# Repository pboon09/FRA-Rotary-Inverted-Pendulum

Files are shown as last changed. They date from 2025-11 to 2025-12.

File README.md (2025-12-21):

# FRA421 Embedded Systems Final Project

## Overview

Advanced embedded system implementation with state estimation filters, multiple interfaces, and safety-critical design for Rotary Inverted Pendulum control.

## Features

### State Estimation
- ✅ **Kalman Filter** - Optimal velocity estimation from encoder positions
- ✅ **Low-Pass Filter** - Noise reduction
- ✅ **CMSIS DSP Library** - Optimized signal processing

### Multi-Interface System
- ✅ **Colors Shield LED (8×8)** - End-effector position visualization
- ✅ **LCD Display** - Real-time joint position and velocity display
- ✅ **SD Card Logging** - Position/velocity data logging
- ✅ **Bluetooth (HC-05)** - Wireless command interface

### Safety & Efficiency
- ✅ **Safety-critical programming** - Fault detection, graceful degradation
- ✅ **Low Power Modes** - Sleep modes during idle periods
- ✅ **Watchdog Timer** - System reliability

### Hardware Integration
- ✅ **Custom PCB** - All interfaces integrated on single board
- ✅ **Non-blocking architecture** - Concurrent interface operation

## System Architecture
```
STM32 NUCLEO-G474RE
    ├─ Encoders (AMT103-V) → Kalman Filter → LQR Controller → Motor
    ├─ LED Matrix → End-effector position (X-Y grid)
    ├─ LCD → Position and velocity display
    ├─ SD Card → CSV data logging
    └─ Bluetooth → Command reception (start/stop/config)
```

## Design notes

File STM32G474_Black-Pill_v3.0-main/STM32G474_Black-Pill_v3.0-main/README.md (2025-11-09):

<!-- Improved compatibility of back to top link: See: https://github.com/othneildrew/Best-README-Template/pull/73 -->

<!--
*** Thanks for checking out the Best-README-Template. If you have a suggestion
*** that would make this better, please fork the repo and create a pull request
*** or simply open an issue with the tag "enhancement".
*** Don't forget to give the project a star!
*** Thanks again! Now go create something AMAZING! :D
-->

<!-- PROJECT SHIELDS -->
<!--
*** I'm using markdown "reference style" links for readability.
*** Reference links are enclosed in brackets [ ] instead of parentheses ( ).
*** See the bottom of this document for the declaration of the reference variables
*** for contributors-url, forks-url, etc. This is an optional, concise syntax you may use.
*** https://www.markdownguide.org/basic-syntax/#reference-style-links
-->
[][contributors-url]
[][forks-url]
[][stars-url]
[][issues-url]
[][license-url]


<!-- PROJECT LOGO -->
<br />
<div align="center">

<h3 align="center">Black Pill v3.0 STM32G474</h3>

  <p align="center">
    The STM32-Pills are compact and convenient for prototyping, but their digital focus leaves room for exploration. The STM32G474's integration of analog and digital components opens up possibilities for creating versatile systems. For example, the integrated opamps and comparators. 
    <br />
    <a href="https://github.com/nikolai2111/STM32G474_Black-Pill_v3.0"><strong>Explore the docs »</strong></a>
    <br />
    <br />
    <a href="https://github.com/nikolai2111/STM32G474_Black-Pill_v3.0">View Demo</a>
    ·
    <a href="https://github.com/nikolai2111/STM32G474_Black-Pill_v3.0/issues/new?labels=bug&template=bug-report---.md">Report Bug</a>
    ·
    <a href="https://github.com/nikolai2111/STM32G474_Black-Pill_v3.0/issues/new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">Request Feature</a>
  </p>
</div>

<!-- TABLE OF CONTENTS -->
<details>
  <summary>Table of Contents</summary>
  <ol>
    <li>
      <a href="#about-the-project">About The Project</a>
      <ul>
        <li><a href="#built-with">Built With</a></li>
      </ul>
    </li>
    <li>
      <a href="#getting-started">Getting Started</a>
      <ul>
        <li><a href="#prerequisites">Prerequisites</a></li>
        <li><a href="#installation">Installation</a></li>
      </ul>
    </li>
    <li><a href="#usage">Usage</a></li>
    <li><a href="#roadmap">Roadmap</a></li>
    <li><a href="#contributing">Contributing</a></li>
    <li><a href="#license">License</a></li>
    <li><a href="#contact">Contact</a></li>
  </ol>
</details>

<!-- ABOUT THE PROJECT -->
## About The Project

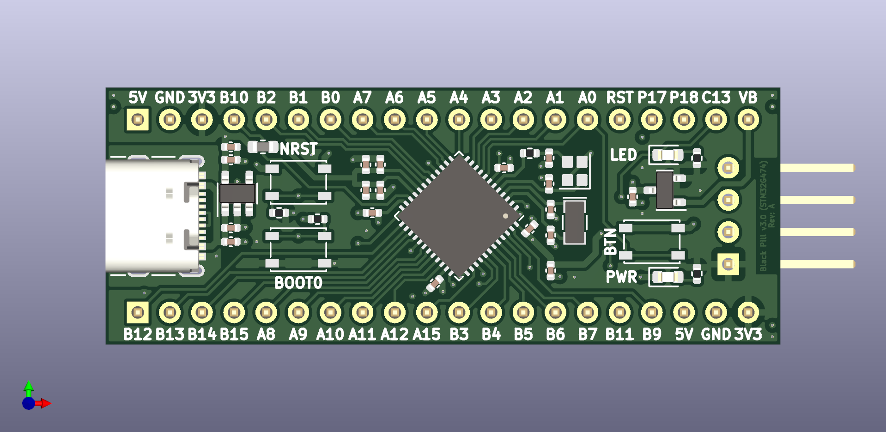
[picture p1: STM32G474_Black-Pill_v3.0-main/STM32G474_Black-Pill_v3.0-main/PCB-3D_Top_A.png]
Product Name Screen Shot
[](https://www.tindie.com/products/nikolai2111/black-pill-v30-stm32g474/)

I find the compact and versatile STM32-Pills (Blue and Black) intriguing due to their ease of use for various applications. They seamlessly integrate into hardware prototypes, simplifying the process of testing ideas. However, I’ve noticed that the existing Black Pills primarily focus on digital tasks.

On the other hand, the STM32G474 stands out as a fascinating microcontroller that bridges the gap between the digital and analog worlds. What piques my interest are its integrated analog components, such as op-amps and comparators, coupled with digital interfaces. This combination offers an exciting opportunity to develop systems that seamlessly blend both digital and analog functionalities.

In summary, while the compact and convenient Pills are fascinating tools for rapid prototyping, their current digital focus leaves room for exploration. In contrast, the STM32G474’s integration of analog and digital components opens up exciting possibilities for creating versatile, boundary-pushing systems.

<p align="right">(<a href="#readme-top">back to top</a>)</p>

### Built With

* [][Kicad-url]

<p align="right">(<a href="#readme-top">back to top</a>)</p>

<!-- GETTING STARTED -->
## Getting Started

### Prerequisites

Install KiCad 8.0 on your computer.

### Installation

ToDo:
1. Clone the repo to your STM32CubeIDE workspace
   ```sh
   git clone https://github.com/nikolai2111/STM32G474_Black-Pill_v3.0.git
   ```
2. Navigate to the the `src` folder.
3. Open the [project file](src/STM32G474_Black-Pill_v3.0.kicad_pro).

<p align="right">(<a href="#readme-top">back to top</a>)</p>

<!-- USAGE EXAMPLES -->
## Usage

Use this dev board with the template from [this repo](https://github.com/nikolai2111/STM32G474_Black-Pill_v3.0_Template). It's an example file.

<p align="right">(<a href="#readme-top">back to top</a>)</p>

<!-- ROADMAP -->
## Roadmap

- [ ] SW: Publish HAL template for this board.
- [ ] SW: Add LL template for this board.

See the [open issues](https://github.com/nikolai2111/STM32G474_Black-Pill_v3.0/issues) for a full list of proposed features (and known issues).

<p align="right">(<a href="#readme-top">back to top</a>)</p>

<!-- CONTRIBUTING -->
## Contributing

Contributions are what make the open source community such an amazing place to learn, inspire, and create. Any contributions you make are **greatly appreciated**.

If you have a suggestion that would make this better, please fork the repo and create a pull request. You can also simply open an issue with the tag "enhancement".
Don't forget to give the project a star! Thanks again!

1. Fork the Project
2. Create your Feature Branch (`git checkout -b feature/AmazingFeature`)
3. Commit your Changes (`git commit -m 'Add some AmazingFeature'`)
4. Push to the Branch (`git push origin feature/AmazingFeature`)
5. Open a Pull Request

<p align="right">(<a href="#readme-top">back to top</a>)</p>

<!-- LICENSE -->
## License

Distributed under the CERN-OHL-P-2.0 License. See `LICENSE.txt` for more information.

<p align="right">(<a href="#readme-top">back to top</a>)</p>

<!-- CONTACT -->
## Contact

Nikolai Zoller - nikolai.zoller@hotmail.com

Project Link: [https://github.com/nikolai2111/STM32G474_Black-Pill_v3.0](https://github.com/nikolai2111/STM32G474_Black-Pill_v3.0)

<p align="right">(<a href="#readme-top">back to top</a>)</p>

---
Source: [Best-README-Template](https://github.com/othneildrew/Best-README-Template)

<!-- MARKDOWN LINKS & IMAGES -->
<!-- https://www.markdownguide.org/basic-syntax/#reference-style-links -->
[contributors-shield]: https://img.shields.io/github/contributors/nikolai2111/STM32G474_Black-Pill_v3.0.svg?style=for-the-badge
[contributors-url]: https://github.com/nikolai2111/STM32G474_Black-Pill_v3.0/graphs/contributors
[forks-shield]: https://img.shields.io/github/forks/nikolai2111/STM32G474_Black-Pill_v3.0.svg?style=for-the-badge
[forks-url]: https://github.com/nikolai2111/STM32G474_Black-Pill_v3.0/network/members
[stars-shield]: https://img.shields.io/github/stars/nikolai2111/STM32G474_Black-Pill_v3.0.svg?style=for-the-badge
[stars-url]: https://github.com/nikolai2111/STM32G474_Black-Pill_v3.0/stargazers
[issues-shield]: https://img.shields.io/github/issues/nikolai2111/STM32G474_Black-Pill_v3.0.svg?style=for-the-badge
[issues-url]: https://github.com/nikolai2111/STM32G474_Black-Pill_v3.0/issues
[license-shield]: https://img.shields.io/github/license/nikolai2111/STM32G474_Black-Pill_v3.0.svg?style=for-the-badge
[license-url]: https://github.com/nikolai2111/STM32G474_Black-Pill_v3.0/blob/master/LICENSE.txt
[product-screenshot]: PCB-3D_Top_A.png
[Kicad-url]: https://www.kicad.org/

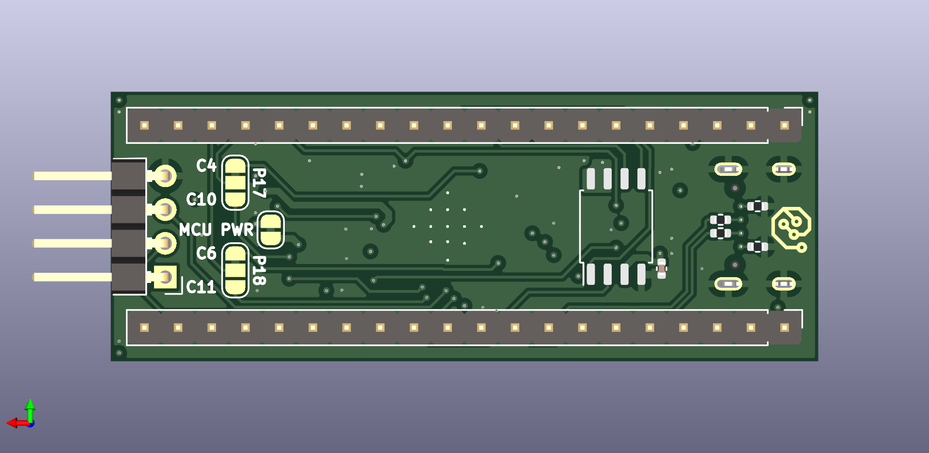
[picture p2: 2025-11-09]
STM32G474_Black-Pill_v3.0-main/STM32G474_Black-Pill_v3.0-main/PCB-3D_Bot_A.png

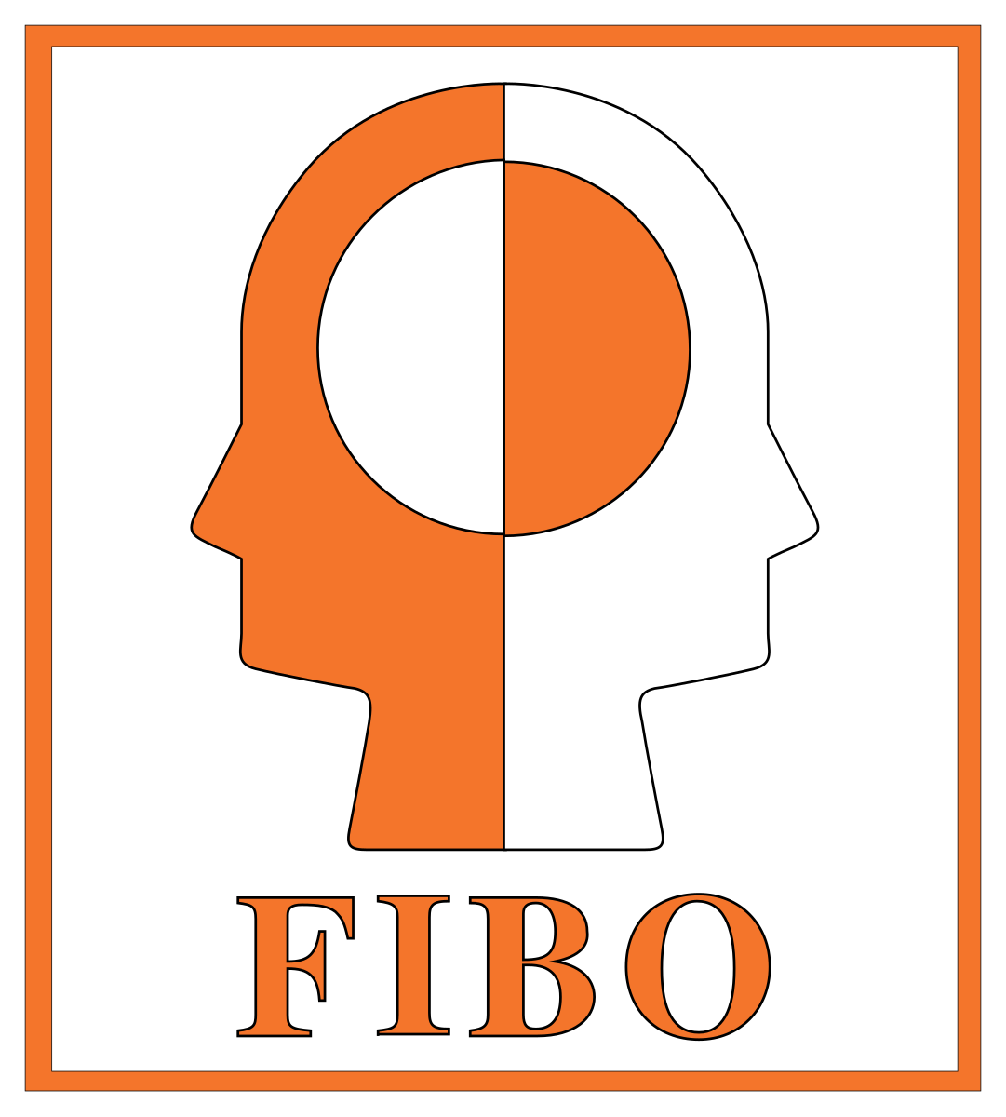
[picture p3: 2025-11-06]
RIP_ExtensionBoard/FIBO.svg.png

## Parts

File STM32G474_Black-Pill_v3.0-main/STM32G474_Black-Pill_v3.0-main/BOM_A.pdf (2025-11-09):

Reference | Value | Footprint | Manufacturer Part no. | Vendor | Vendor Part No. | Qty
C101, C104, C108-C110, C112, C114, C115, C119, C120 | 100nF | Capacitor_SMD:C_0402_1005Metric | GRM155R71C104KA88D | Digikey | 490-3261-1-ND | 10
C102, C103, C105, C106 | 6pF | Capacitor_SMD:C_0402_1005Metric | GRM1555C1H6R0BA01D | Digikey | 490-8221-1-ND | 4
C107 | 10µF | Capacitor_SMD:C_0402_1005Metric | GRM155R60J106ME15D | Digikey | 490-13238-1-ND | 1
C113, C116-C118 | 1µF | Capacitor_SMD:C_0402_1005Metric | GRM155C81C105KE11D | Digikey | 490-12700-1-ND | 4
D101 | red | LED_SMD:LED_0603_1608Metric | LTST-C190KRKT | Digikey | 160-1436-1-ND | 1
D102 | BAT54C | Package_TO_SOT_SMD:SOT-23 | BAT54C | Digikey | 4878-BAT54CCT-ND | 1
D103 | green | LED_SMD:LED_0603_1608Metric | LTST-C190KGKT | Digikey | 160-1435-1-ND | 1
J101 | USB_C_Receptacle_USB2.0 | Connector_USB:USB_C_Receptacle_GCT_USB4105-xx-A_16P_TopMnt_Horizontal | USB4105-GF-A | Digikey | 2073-USB4105-GF-ACT-ND | 1
J102, J103 | Conn_01x20 | Connector_PinHeader_2.54mm:PinHeader_1x20_P2.54mm_Vertical | - | From stock | - | 2
J104 | Conn_01x04 | Connector_PinHeader_2.54mm_User:PinHeader_1x04_P2.54mm_Horizontal_Board_Edge | - | From stock | - | 1
L101 | 10µH | Inductor_SMD:L_0603_1608Metric | MLZ1608M100WT000 | Digikey | 445-6389-1-ND | 1
R101, R102 | 5.1k | Resistor_SMD:R_0402_1005Metric | RC0402FR-075K1L | Digikey | 311-5.10KLRCT-ND | 2
R103, R108 | 10k | Resistor_SMD:R_0402_1005Metric | RC0402FR-0710KL | Digikey | 311-10.0KLRCT-ND | 2
R104, R105 | 10R | Resistor_SMD:R_0402_1005Metric | RC0402FR-0710RL | Digikey | 311-10.0LRCT-ND | 2
R106 | 0R | Resistor_SMD:R_0402_1005Metric | RC0402FR-070RL | Digikey | 311-0.0LRCT-ND | 1
R107, R109 | 100R | Resistor_SMD:R_0402_1005Metric | RC0402FR-07100RL | Digikey | 311-100LRCT-ND | 2
SW101-SW103 | SW_Push | Button_Switch_SMD:SW_SPST_PTS810 | PTS810 SJK 250 SMTR LFS | Digikey | CKN10503CT-ND | 3
U101 | W25Q32JVSS | Package_SO:SOIC-8_5.23x5.23mm_P1.27mm | W25Q32JVSSIQ | Digikey | W25Q32JVSSIQ-ND | 1
U102 | STM32G474CEUx | Package_DFN_QFN:QFN-48-1EP_7x7mm_P0.5mm_EP5.6x5.6mm | STM32G474CEU6 | Digikey | 497-STM32G474CEU6-ND | 1
U103 | AP7343xx | Package_TO_SOT_SMD:SOT-23-5 | AP7343-33W5-7 | Digikey | AP7343-33W5-7DICT-ND | 1
Y101 | 24MHz | Crystal:Crystal_SMD_SeikoEpson_FA128-4Pin_2.0x1.6mm | NX2016SA-24MHZ-EXS00A-CS10820 | Digikey | 644-1365-1-ND | 1
Y102 | 32.768kHz | Crystal:Crystal_SMD_MicroCrystal_CC7V-T1A-2Pin_3.2x1.5mm | NX3215SA-32.768KHZ-EXS00A-MU00525 | Digikey | 644-1386-1-ND | 1

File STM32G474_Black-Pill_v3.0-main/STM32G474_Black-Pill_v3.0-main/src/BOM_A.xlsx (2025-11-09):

Reference | Value | Footprint | Datasheet | Manufacturer Part no. | Vendor | Vendor Part No. | Qty
C101, C104, C108-C110, C112, C114, C115, C119, C120 | 100nF | Capacitor_SMD:C_0402_1005Metric | ~ | GRM155R71C104KA88D | Digikey | 490-3261-1-ND | 10
C102, C103, C105, C106 | 6pF | Capacitor_SMD:C_0402_1005Metric | ~ | GRM1555C1H6R0BA01D | Digikey | 490-8221-1-ND | 4
C107 | 10µF | Capacitor_SMD:C_0402_1005Metric | ~ | GRM155R60J106ME15D | Digikey | 490-13238-1-ND | 1
C113, C116-C118 | 1µF | Capacitor_SMD:C_0402_1005Metric | ~ | GRM155C81C105KE11D | Digikey | 490-12700-1-ND | 4
D101 | red | LED_SMD:LED_0603_1608Metric | ~ | LTST-C190KRKT | Digikey | 160-1436-1-ND | 1
D102 | BAT54C | Package_TO_SOT_SMD:SOT-23 | http://www.diodes.com/_files/datasheets/ds11005.pdf | BAT54C | Digikey | 4878-BAT54CCT-ND | 1
D103 | green | LED_SMD:LED_0603_1608Metric | ~ | LTST-C190KGKT | Digikey | 160-1435-1-ND | 1
J101 | USB_C_Receptacle_USB2.0 | Connector_USB:USB_C_Receptacle_GCT_USB4105-xx-A_16P_TopMnt_Horizontal | https://www.usb.org/sites/default/files/documents/usb_type-c.zip | USB4105-GF-A | Digikey | 2073-USB4105-GF-ACT-ND | 1
J102, J103 | Conn_01x20 | Connector_PinHeader_2.54mm:PinHeader_1x20_P2.54mm_Vertical | ~ | - | From stock | - | 2
J104 | Conn_01x04 | Connector_PinHeader_2.54mm_User:PinHeader_1x04_P2.54mm_Horizontal_Board_Edge | ~ | - | From stock | - | 1
JP101, JP102 | SolderJumper_3_Bridged12 | Jumper:SolderJumper-3_P1.3mm_Bridged12_RoundedPad1.0x1.5mm_NumberLabels | ~ | - | - | - | 2
JP103 | SolderJumper_2_Bridged | Jumper:SolderJumper-2_P1.3mm_Bridged_RoundedPad1.0x1.5mm | ~ | - | - | - | 1
L101 | 10µH | Inductor_SMD:L_0603_1608Metric | ~ | MLZ1608M100WT000 | Digikey | 445-6389-1-ND | 1
R101, R102 | 5.1k | Resistor_SMD:R_0402_1005Metric | ~ | RC0402FR-075K1L | Digikey | 311-5.10KLRCT-ND | 2
R103, R108 | 10k | Resistor_SMD:R_0402_1005Metric | ~ | RC0402FR-0710KL | Digikey | 311-10.0KLRCT-ND | 2
R104, R105 | 10R | Resistor_SMD:R_0402_1005Metric | ~ | RC0402FR-0710RL | Digikey | 311-10.0LRCT-ND | 2
R106 | 0R | Resistor_SMD:R_0402_1005Metric | ~ | RC0402FR-070RL | Digikey | 311-0.0LRCT-ND | 1
R107, R109 | 100R | Resistor_SMD:R_0402_1005Metric | ~ | RC0402FR-07100RL | Digikey | 311-100LRCT-ND | 2
SW101-SW103 | SW_Push | Button_Switch_SMD:SW_SPST_PTS810 | ~ | PTS810 SJK 250 SMTR LFS | Digikey | CKN10503CT-ND | 3
U101 | W25Q32JVSS | Package_SO:SOIC-8_5.23x5.23mm_P1.27mm | http://www.winbond.com/resource-files/w25q32jv%20revg%2003272018%20plus.pdf | W25Q32JVSSIQ | Digikey | W25Q32JVSSIQ-ND | 1
U102 | STM32G474CEUx | Package_DFN_QFN:QFN-48-1EP_7x7mm_P0.5mm_EP5.6x5.6mm | https://www.st.com/resource/en/datasheet/stm32g474ce.pdf | STM32G474CEU6 | Digikey | 497-STM32G474CEU6-ND | 1
U103 | AP7343xx | Package_TO_SOT_SMD:SOT-23-5 | https://www.diodes.com/assets/Datasheets/AP7343.pdf | AP7343-33W5-7 | Digikey | AP7343-33W5-7DICT-ND | 1
Y101 | 24MHz | Crystal:Crystal_SMD_SeikoEpson_FA128-4Pin_2.0x1.6mm | ~ | NX2016SA-24MHZ-EXS00A-CS10820 | Digikey | 644-1365-1-ND | 1
Y102 | 32.768kHz | Crystal:Crystal_SMD_MicroCrystal_CC7V-T1A-2Pin_3.2x1.5mm | ~ | NX3215SA-32.768KHZ-EXS00A-MU00525 | Digikey | 644-1386-1-ND | 1

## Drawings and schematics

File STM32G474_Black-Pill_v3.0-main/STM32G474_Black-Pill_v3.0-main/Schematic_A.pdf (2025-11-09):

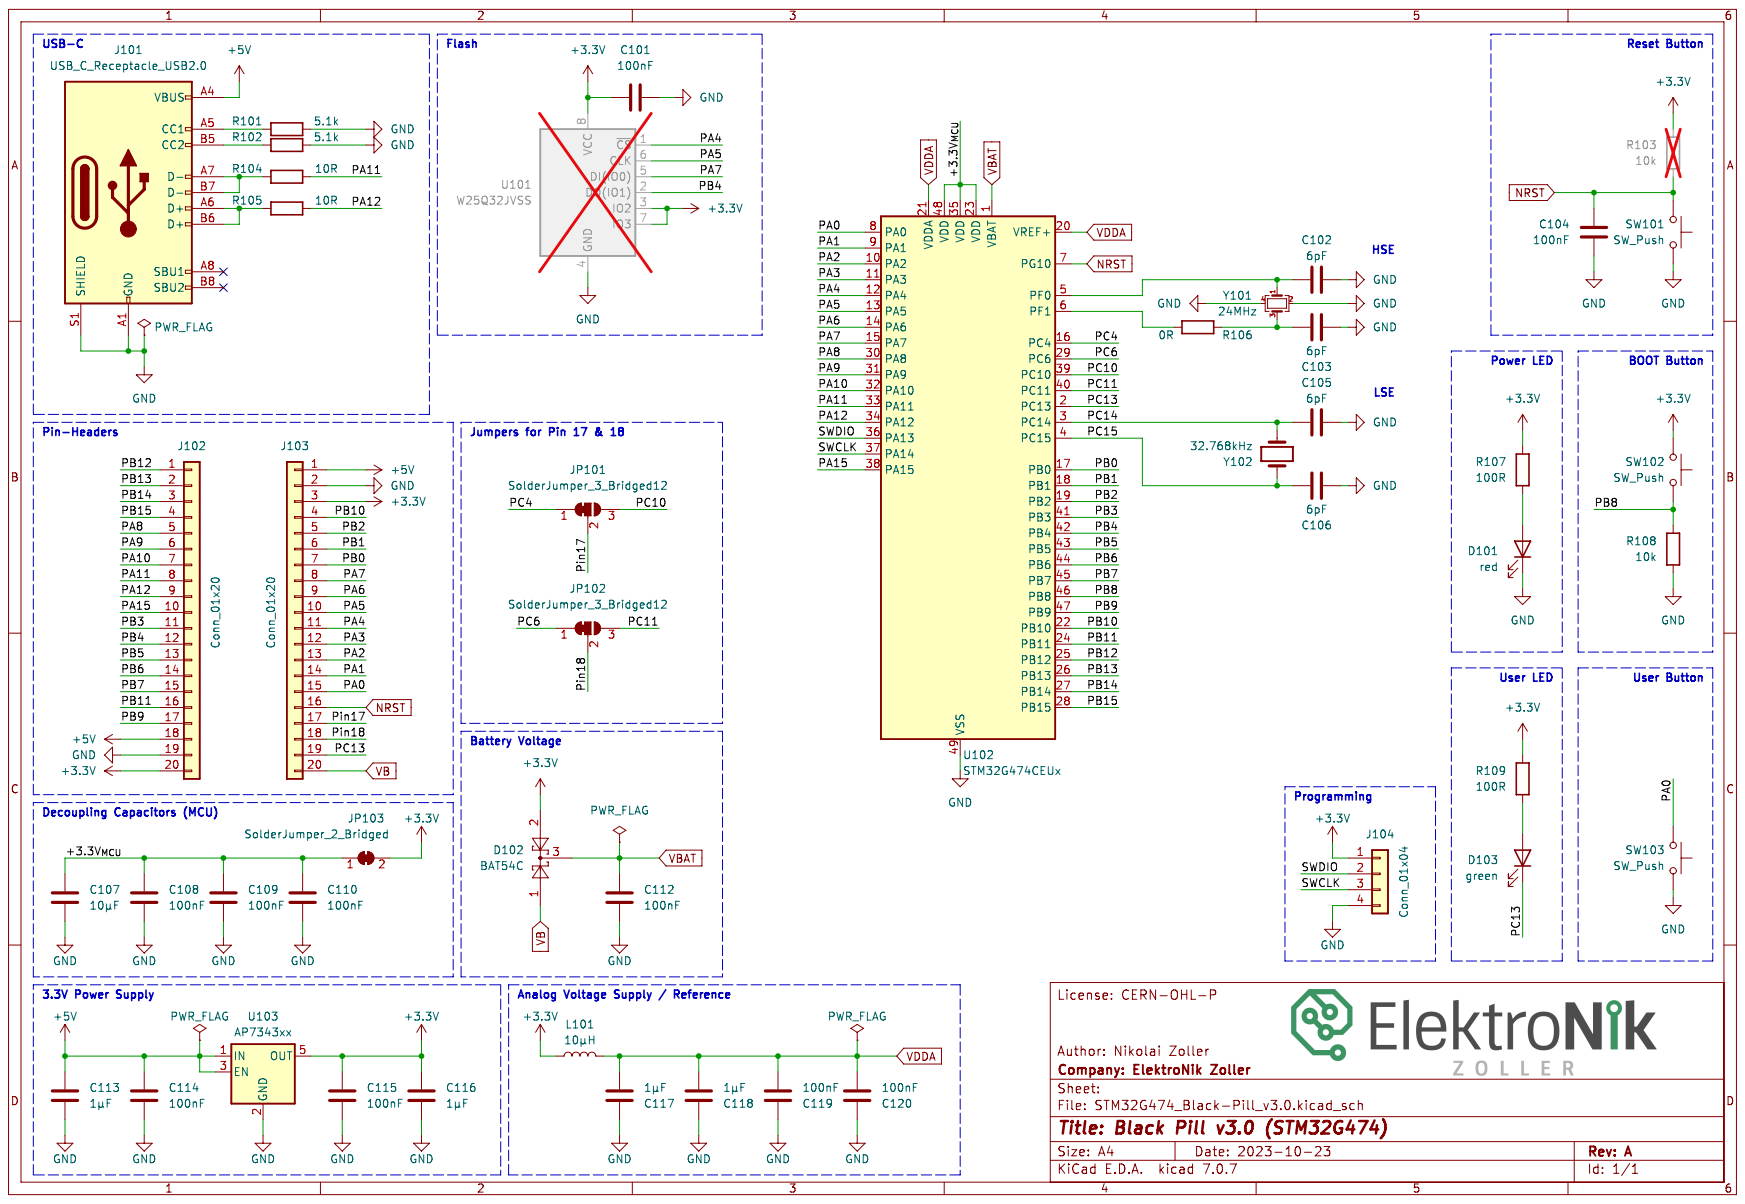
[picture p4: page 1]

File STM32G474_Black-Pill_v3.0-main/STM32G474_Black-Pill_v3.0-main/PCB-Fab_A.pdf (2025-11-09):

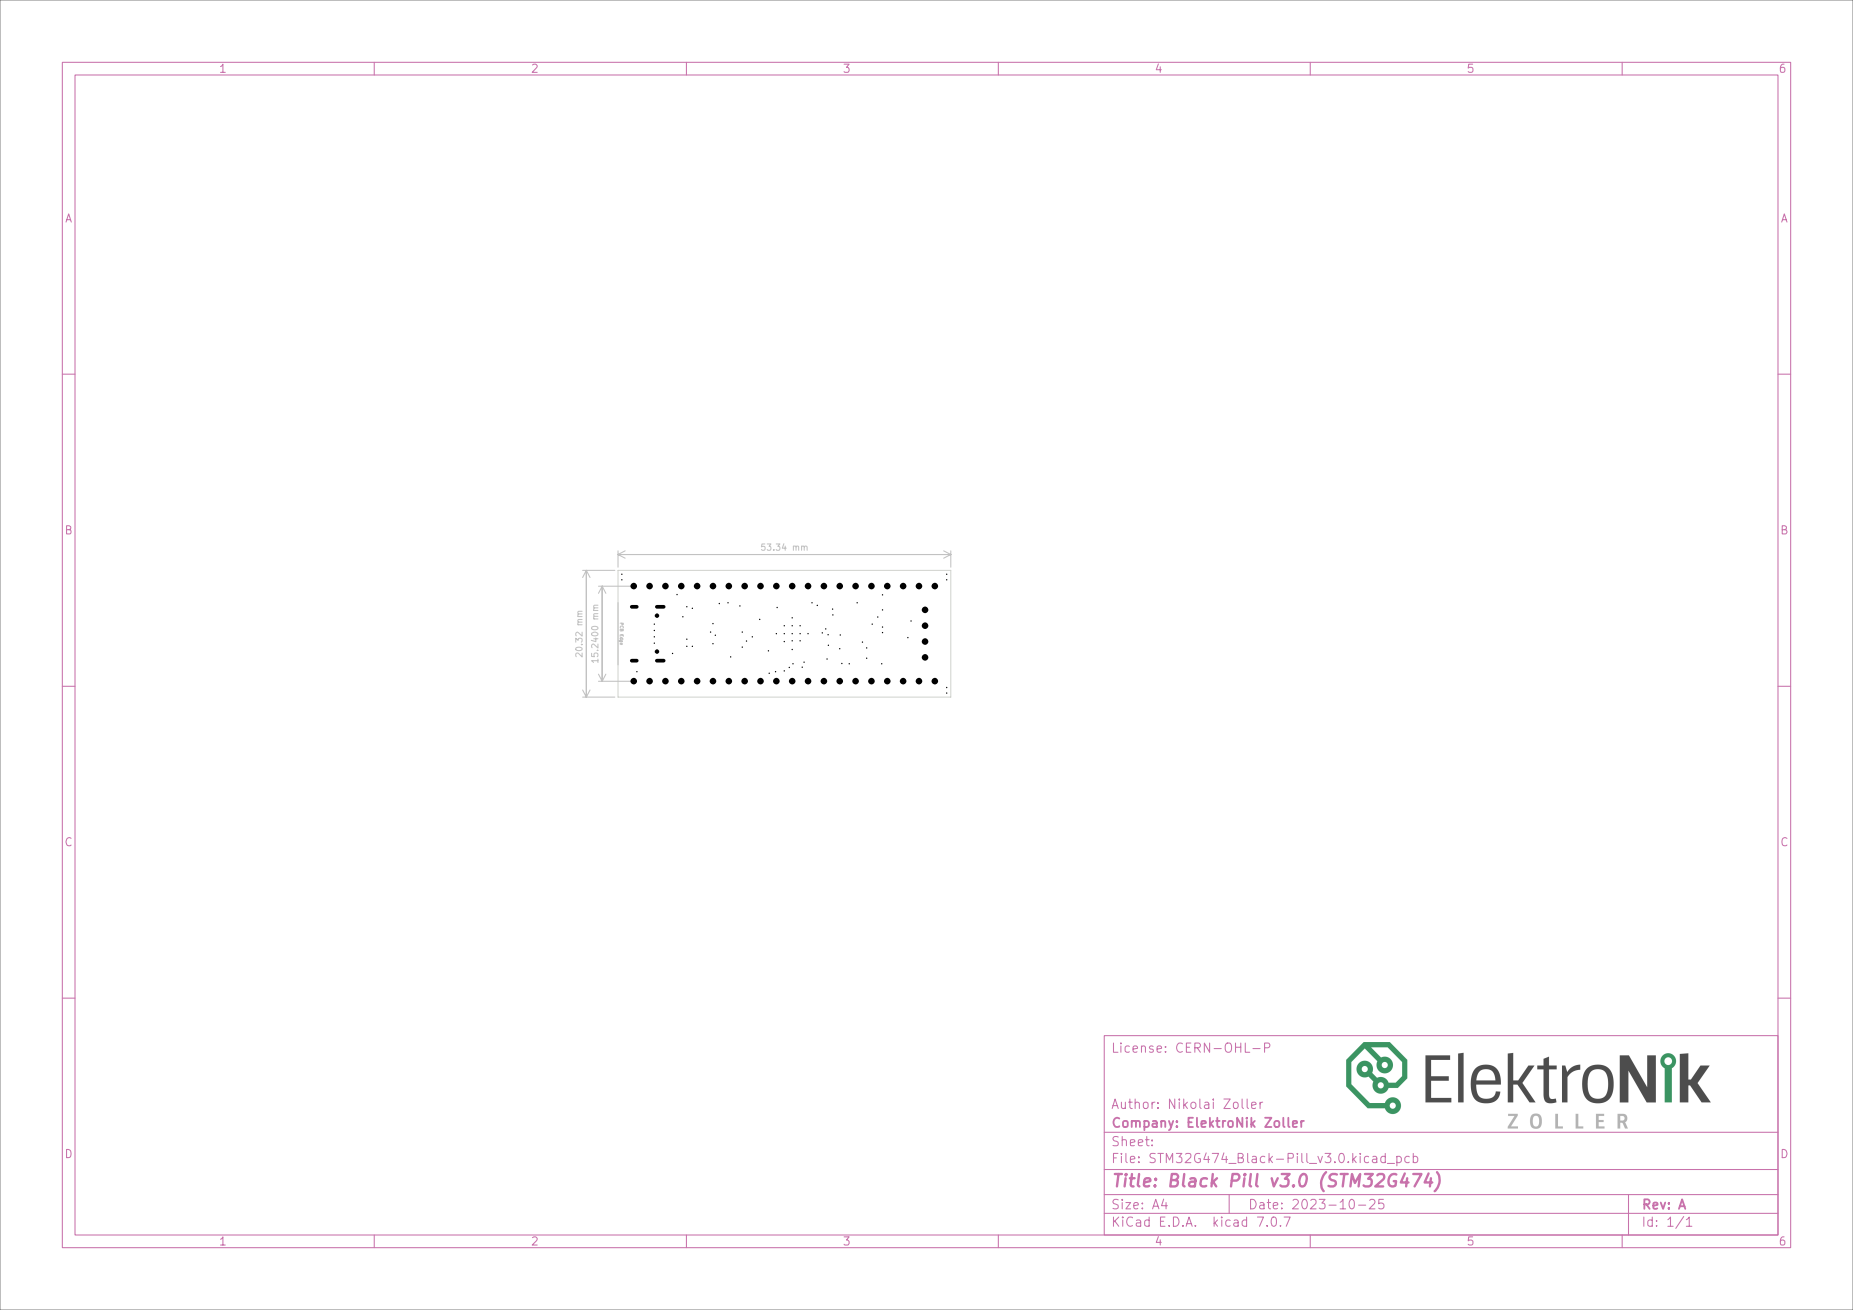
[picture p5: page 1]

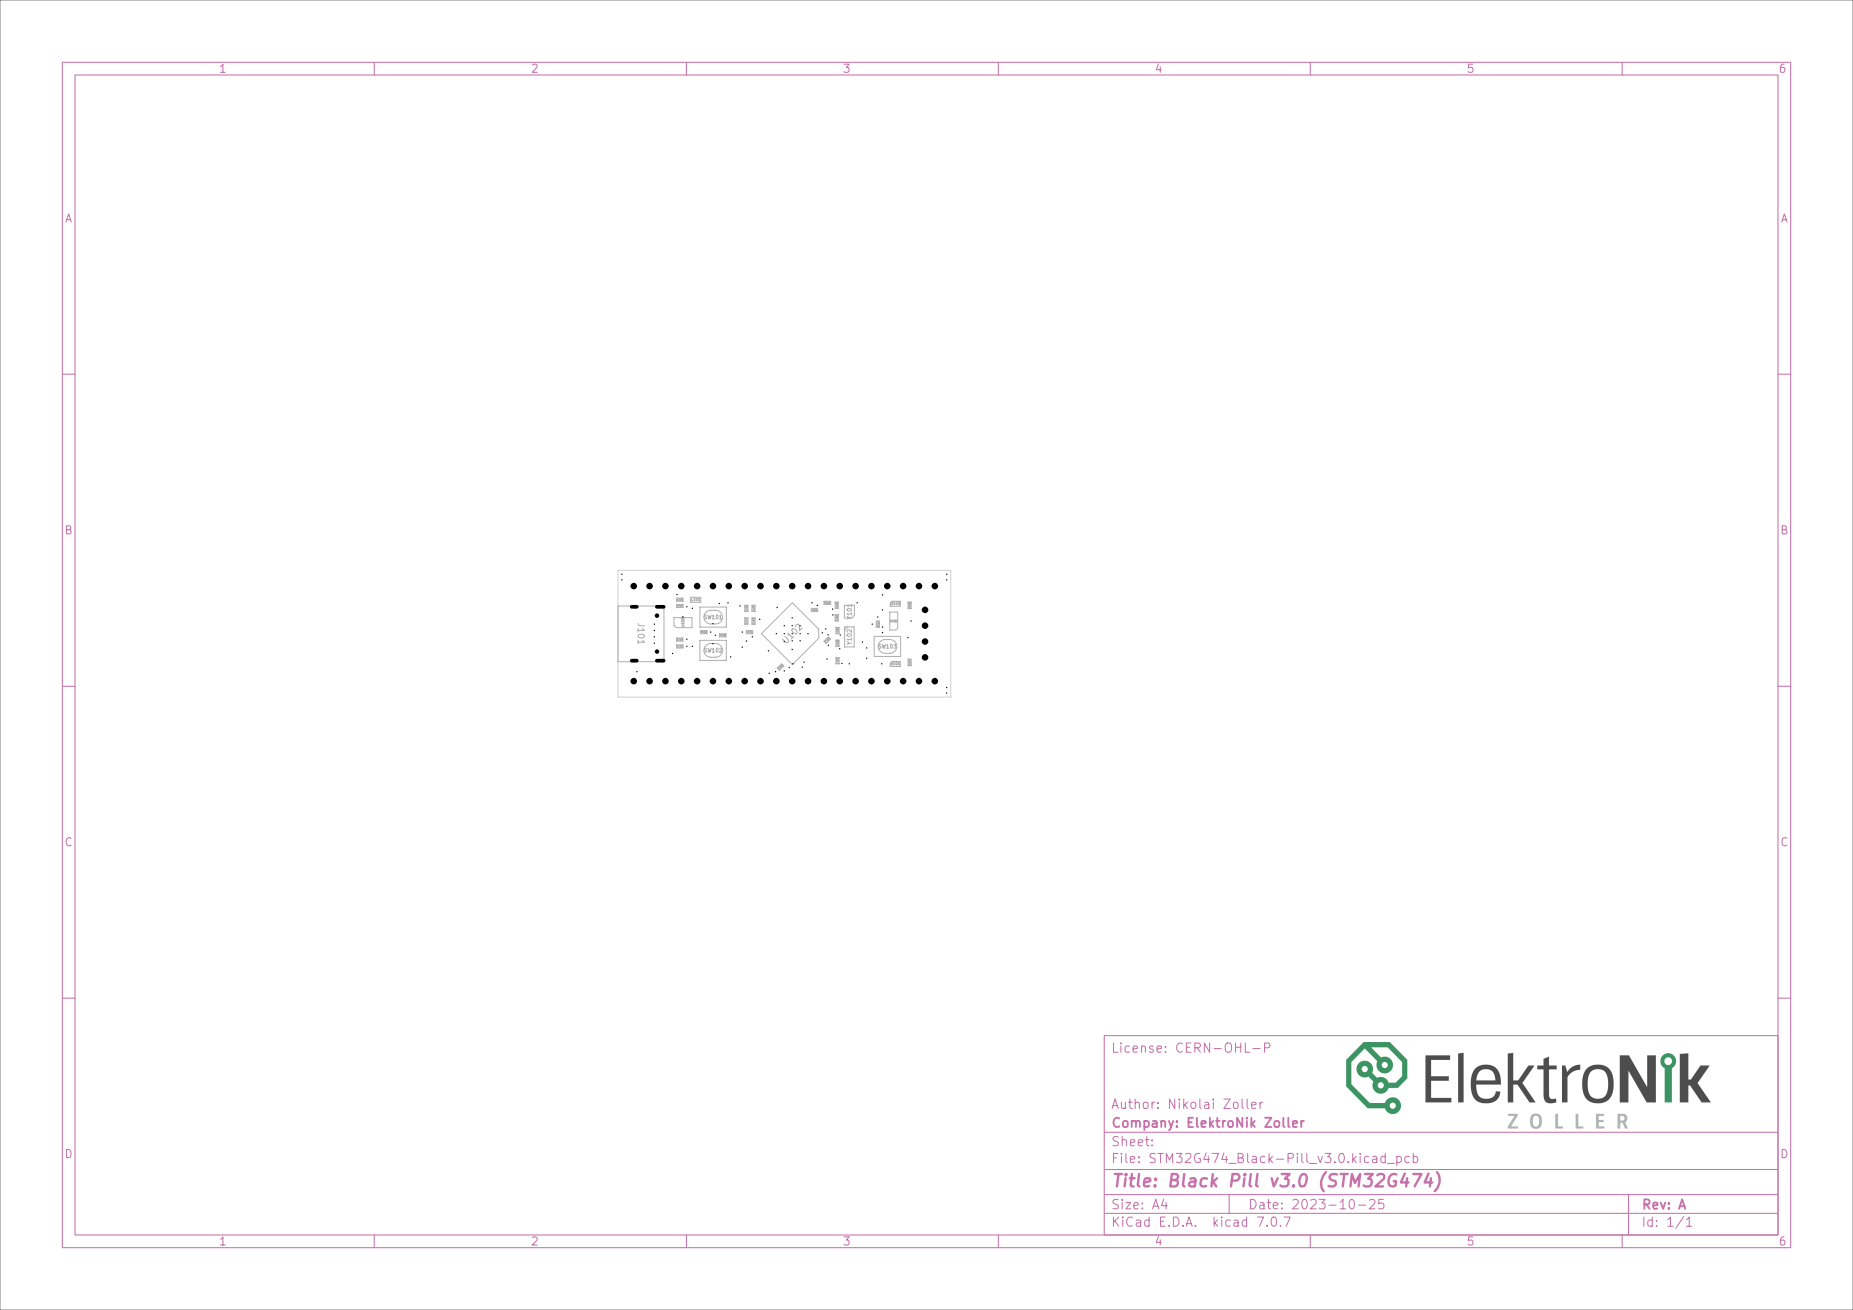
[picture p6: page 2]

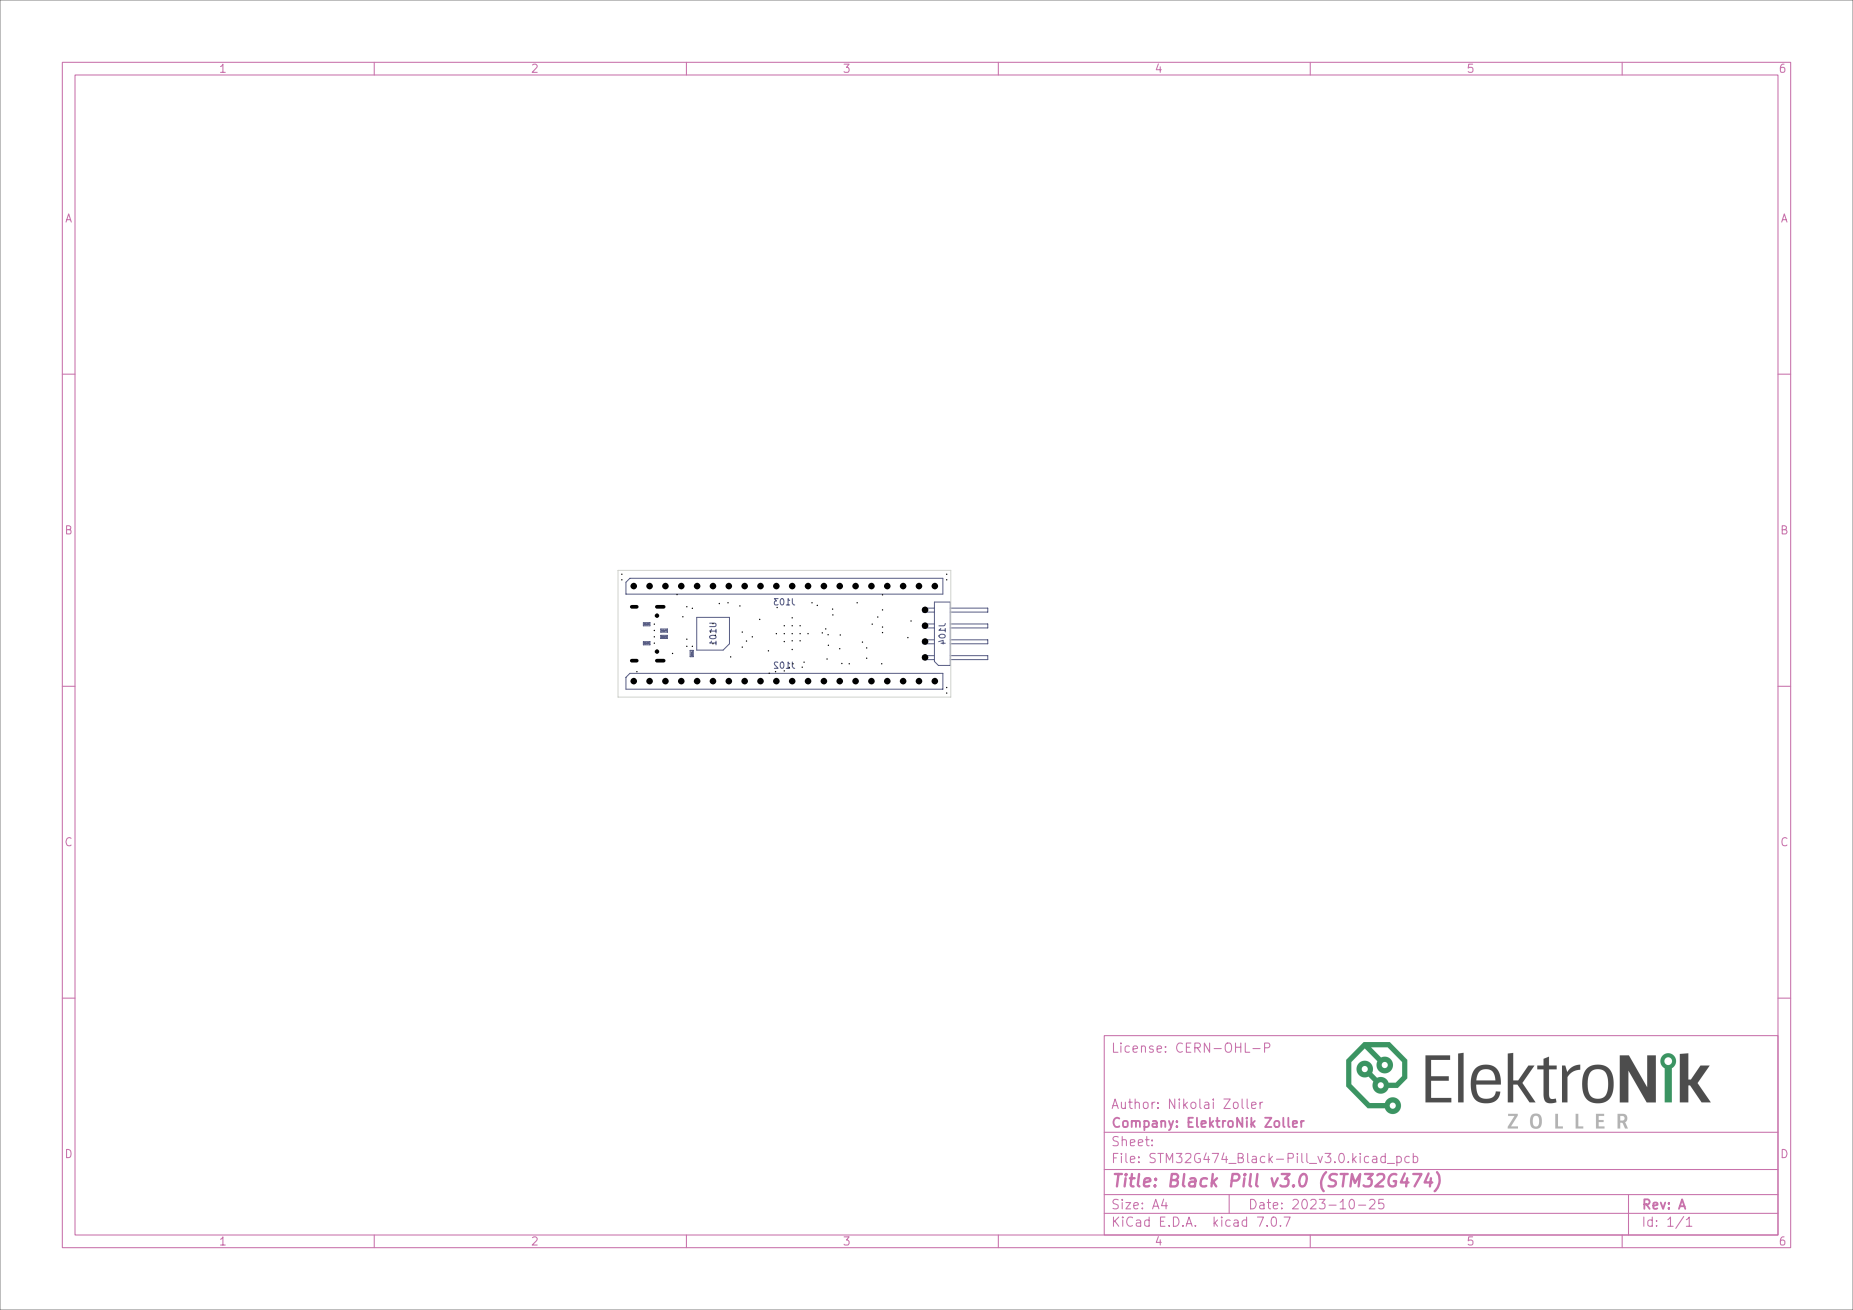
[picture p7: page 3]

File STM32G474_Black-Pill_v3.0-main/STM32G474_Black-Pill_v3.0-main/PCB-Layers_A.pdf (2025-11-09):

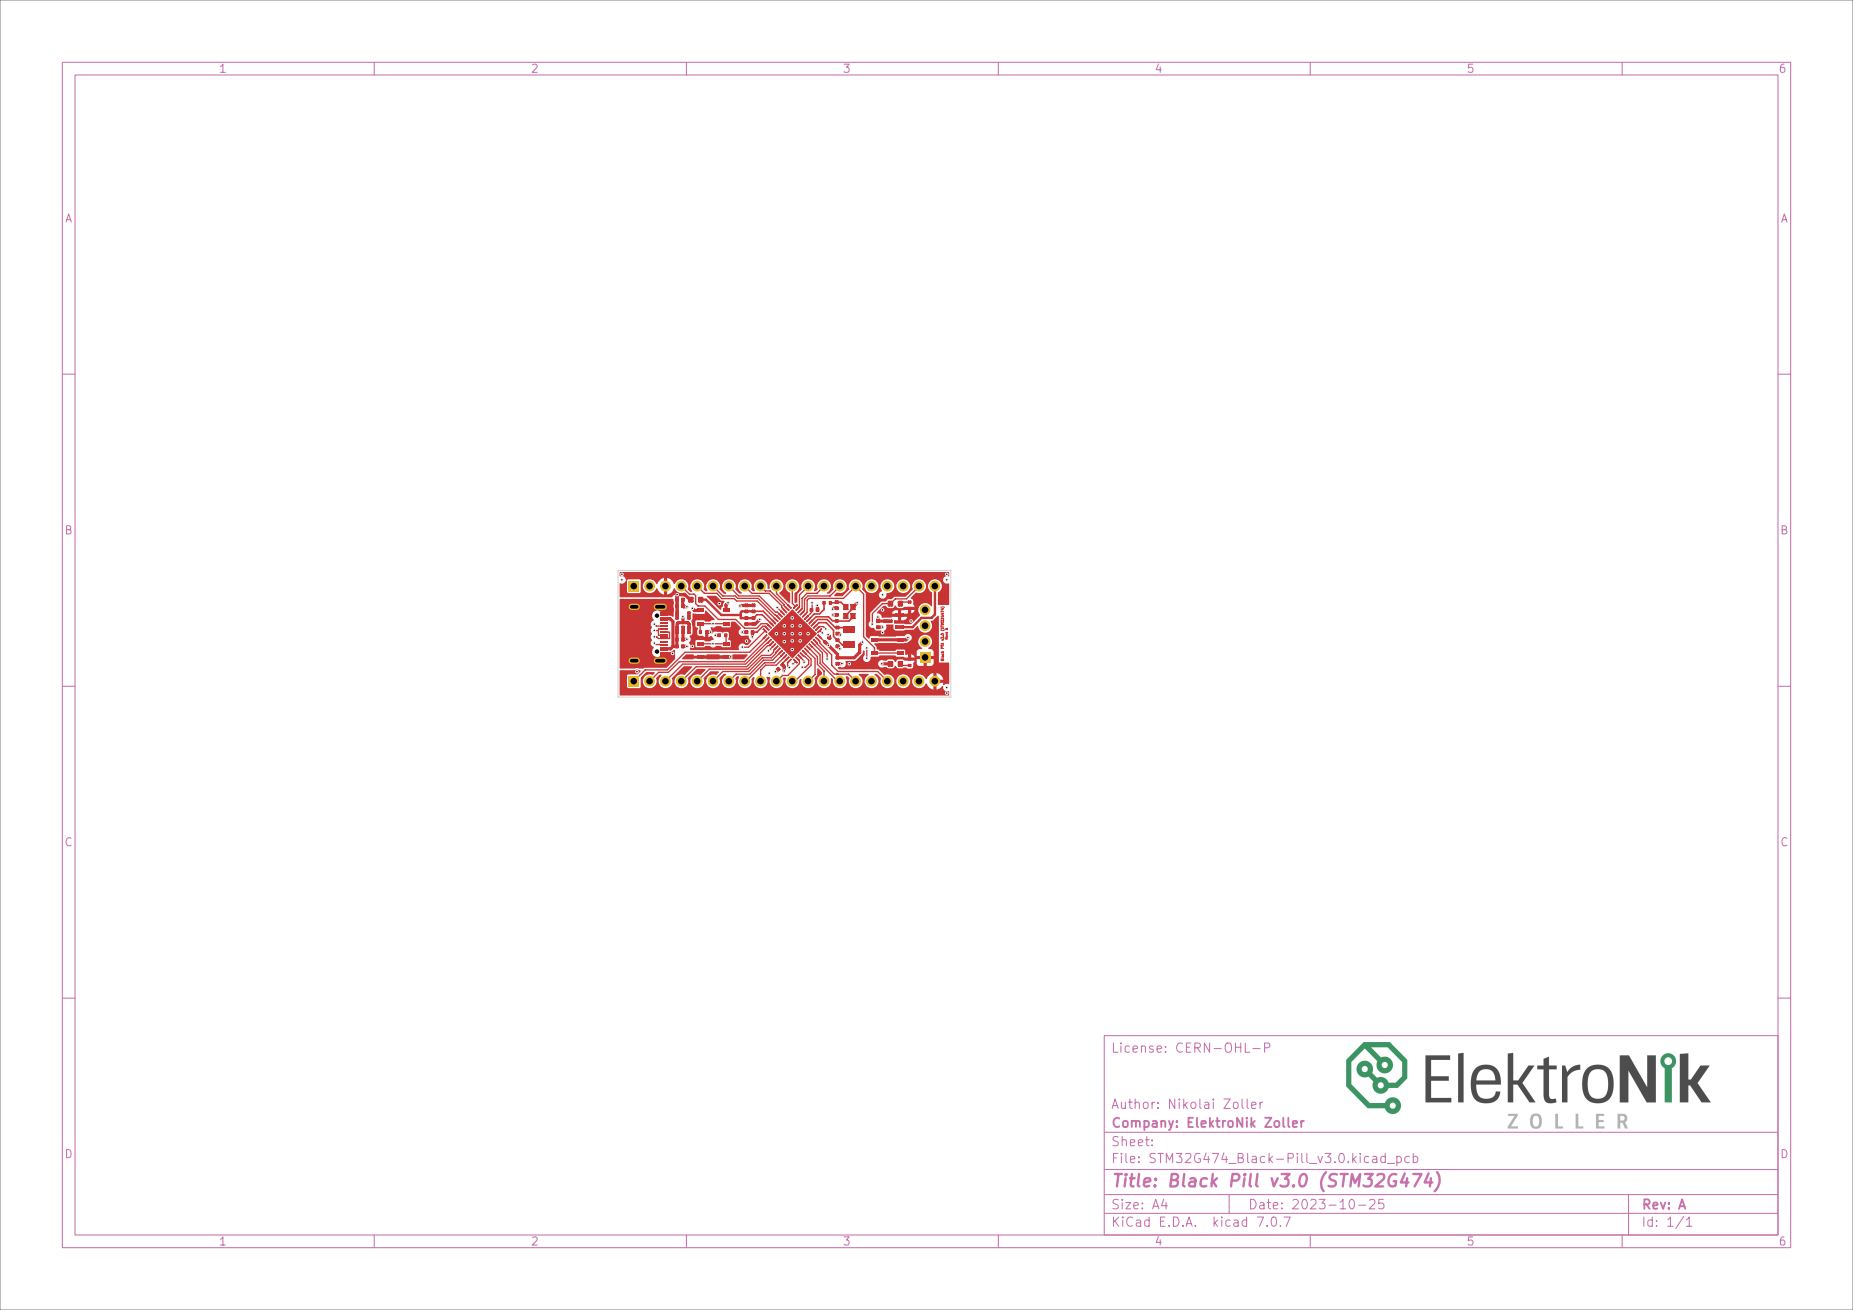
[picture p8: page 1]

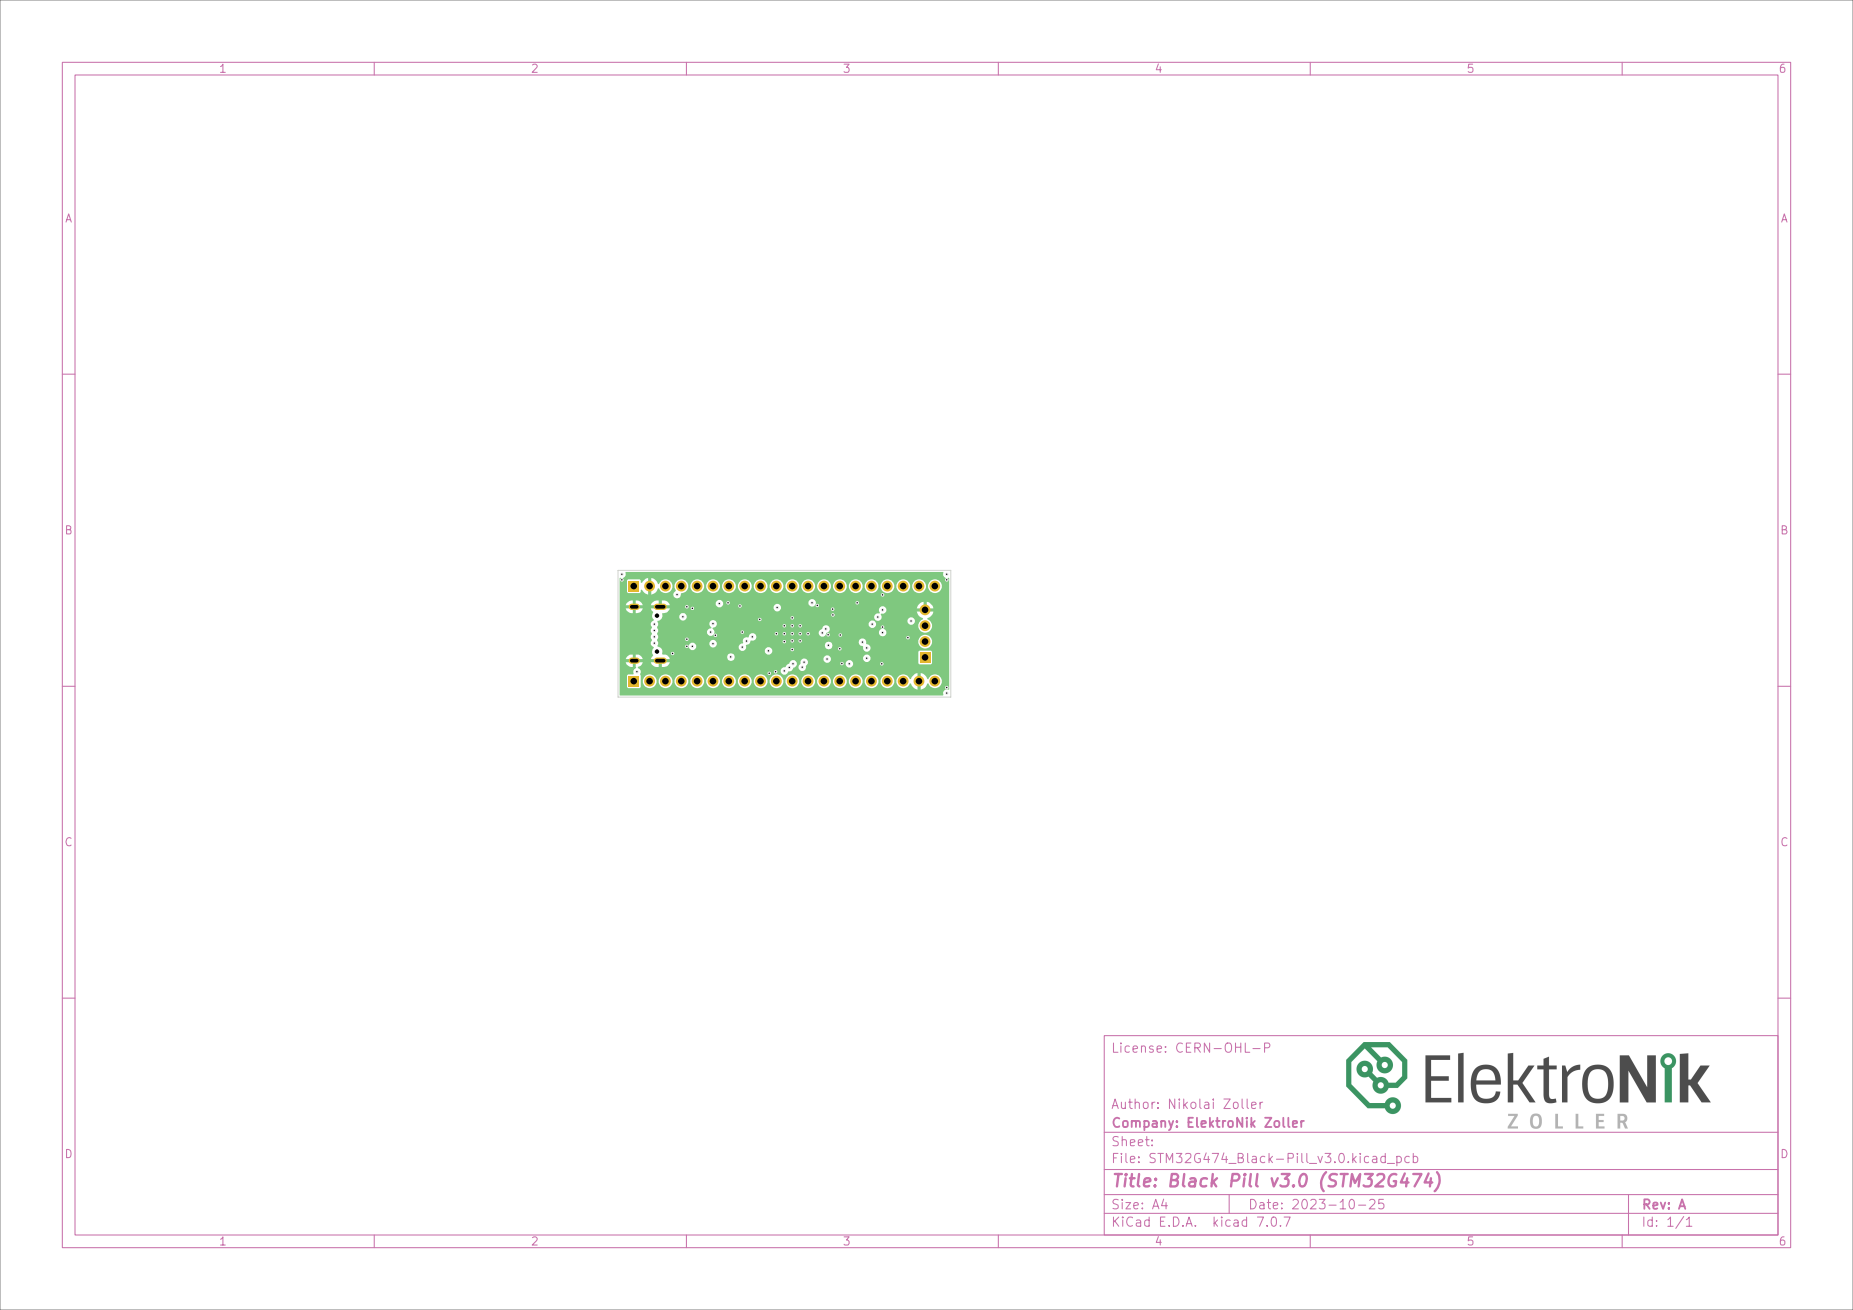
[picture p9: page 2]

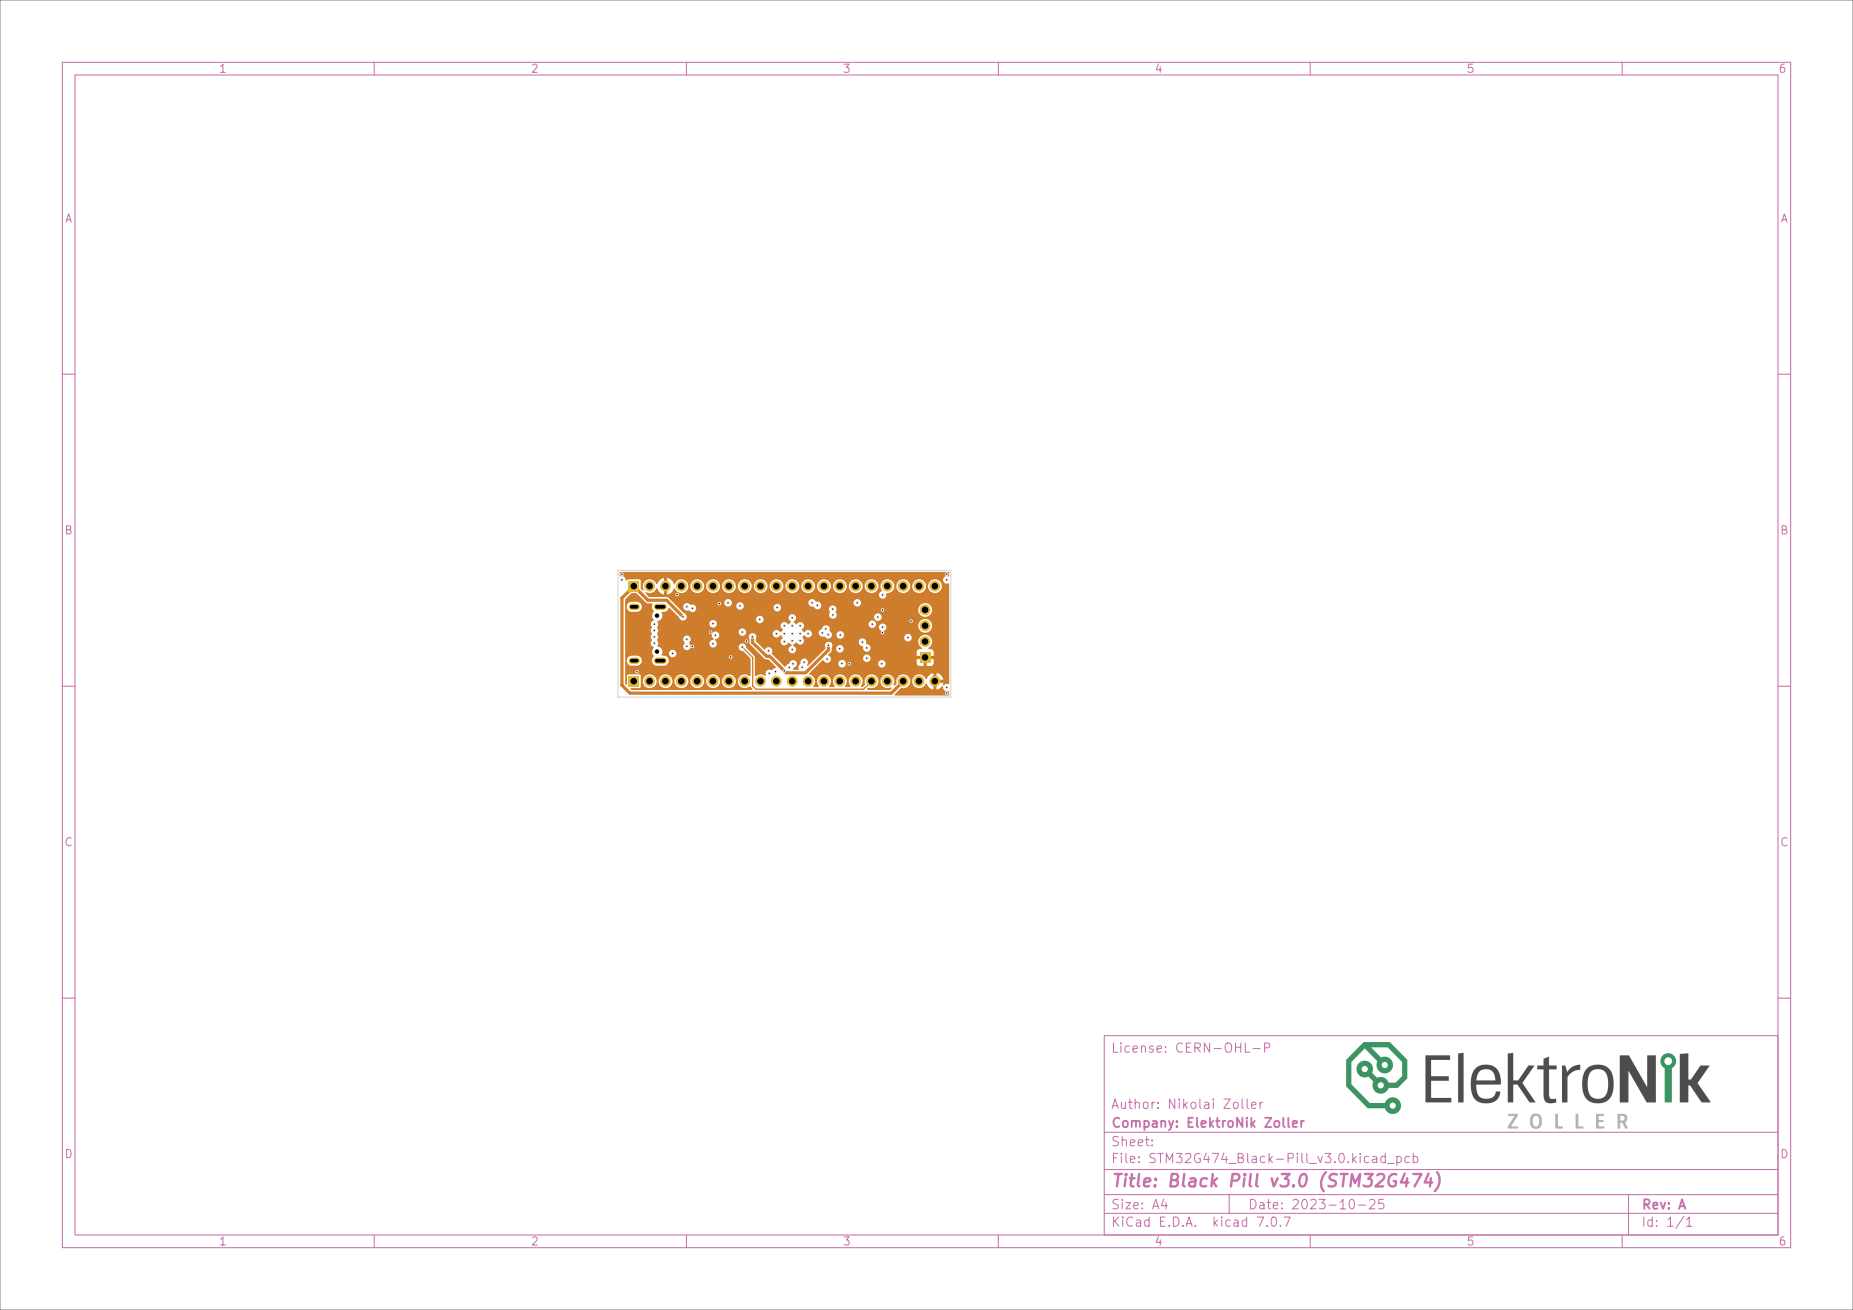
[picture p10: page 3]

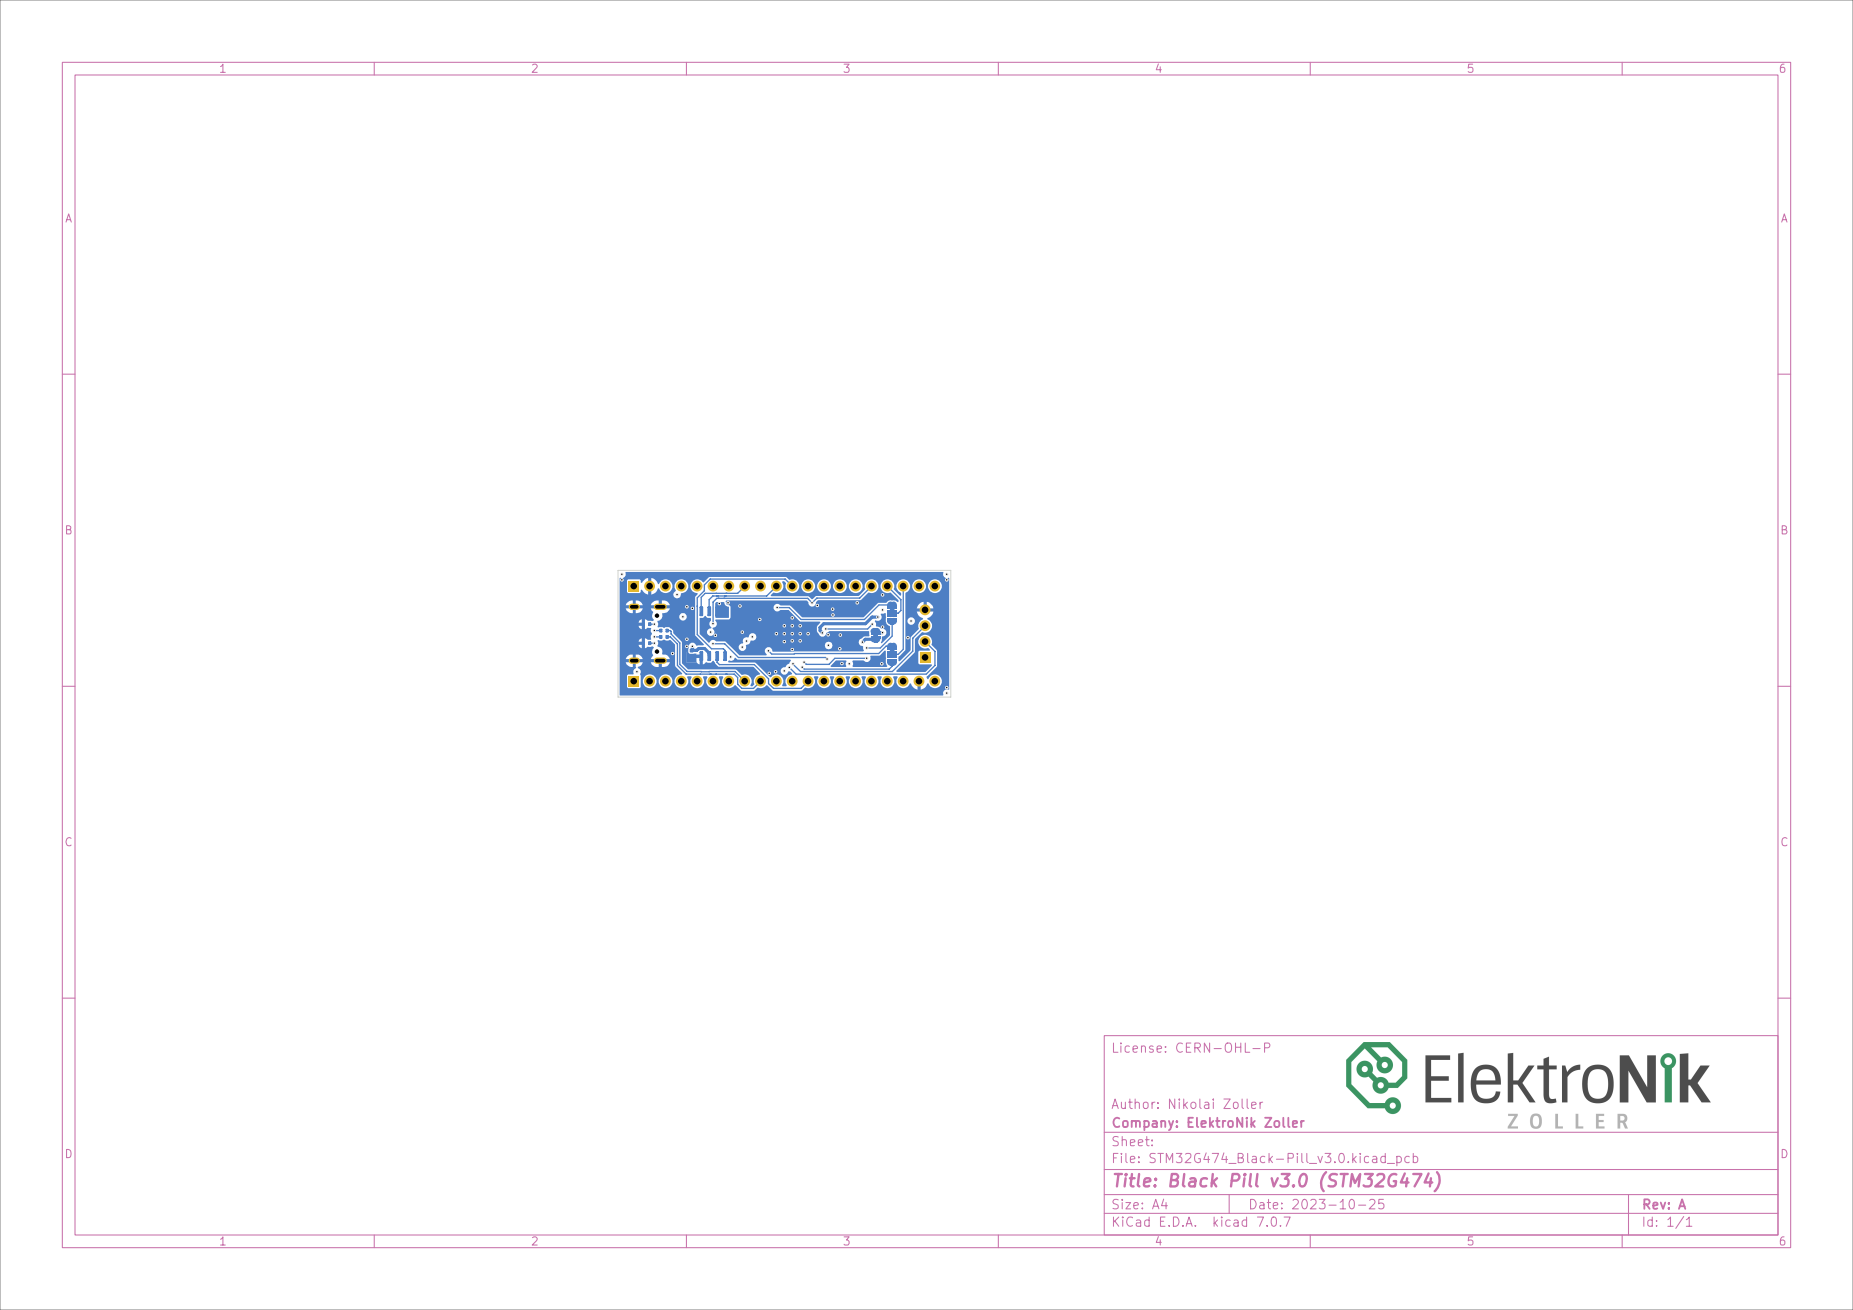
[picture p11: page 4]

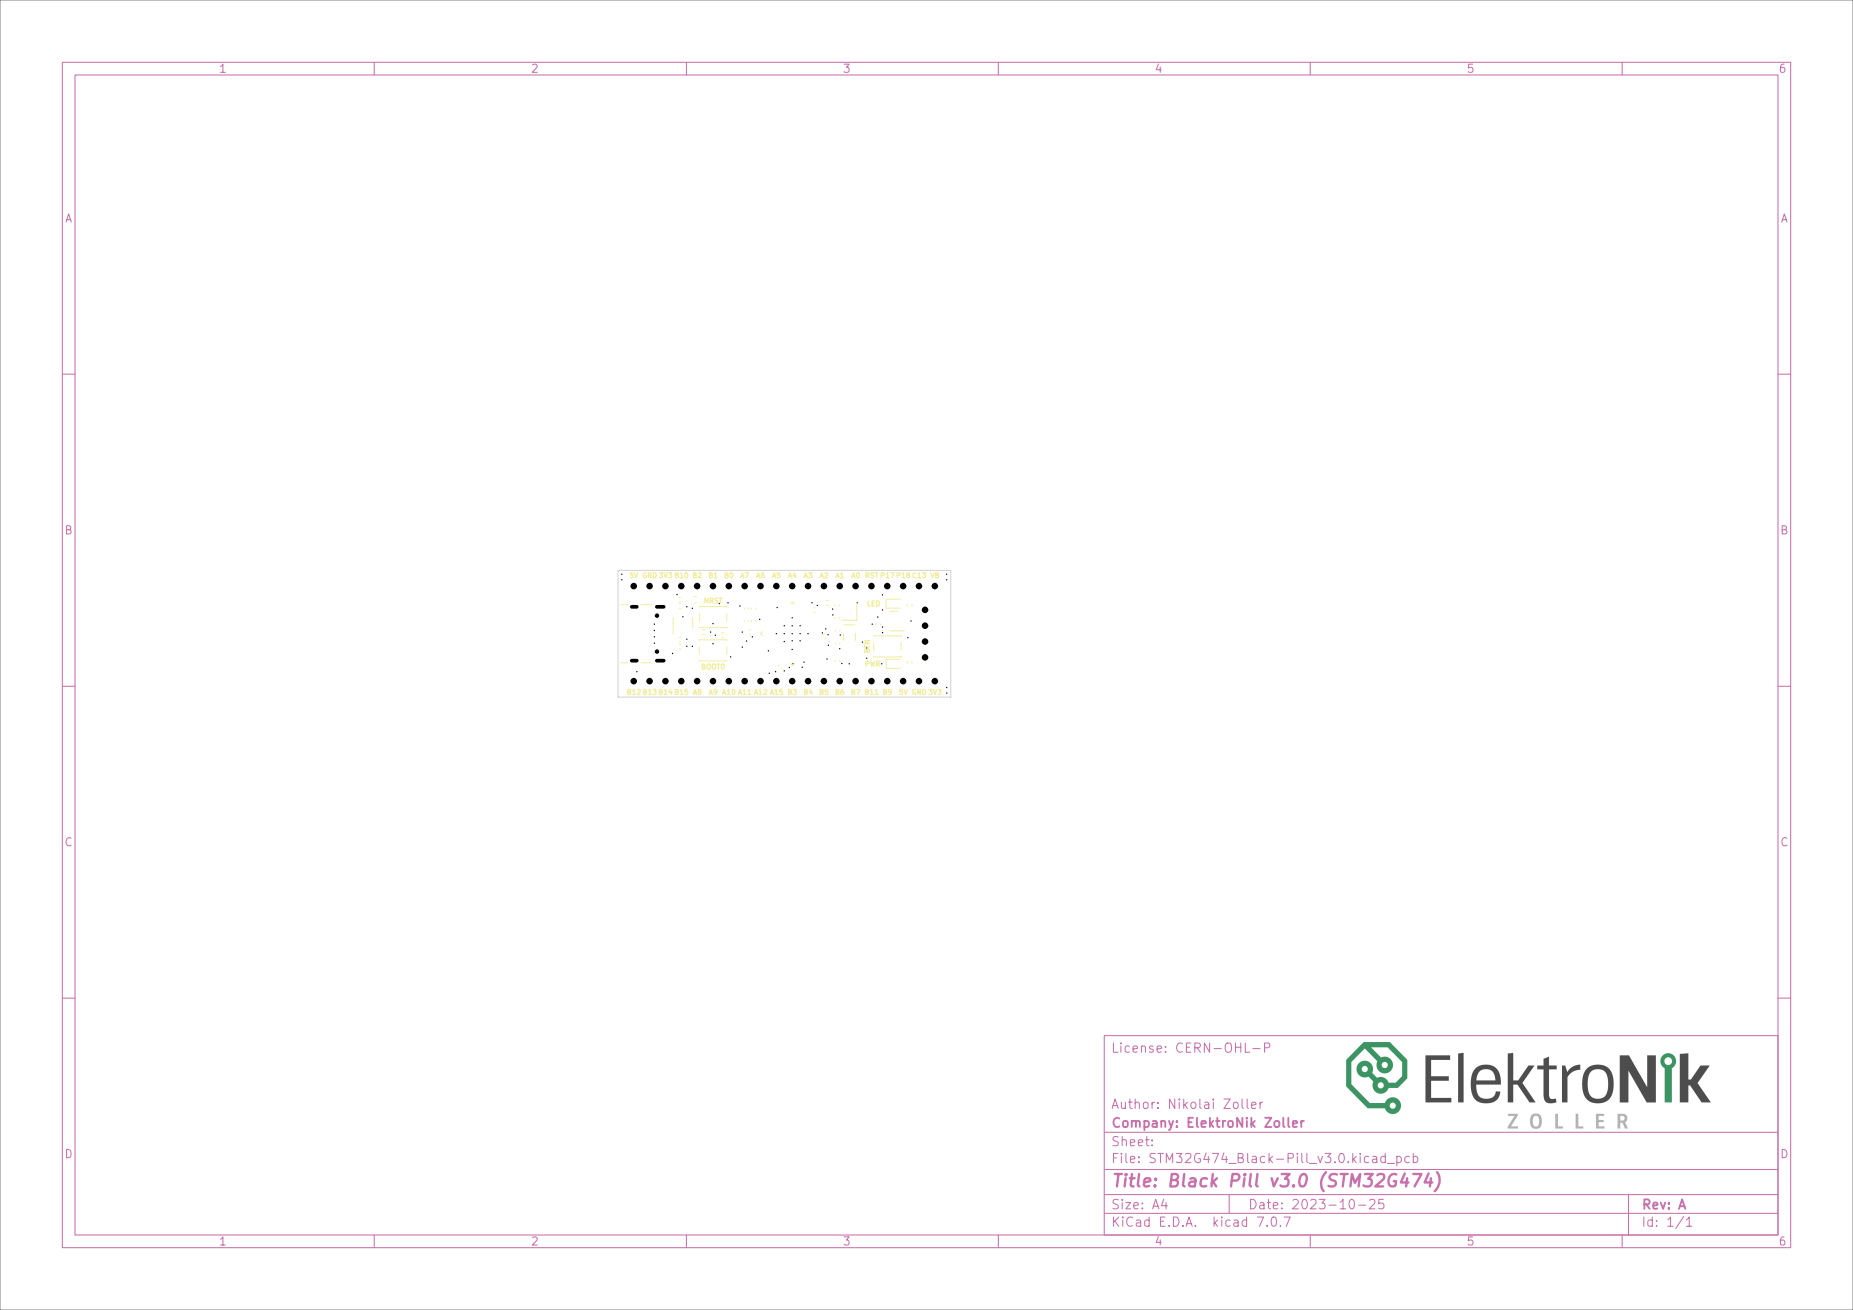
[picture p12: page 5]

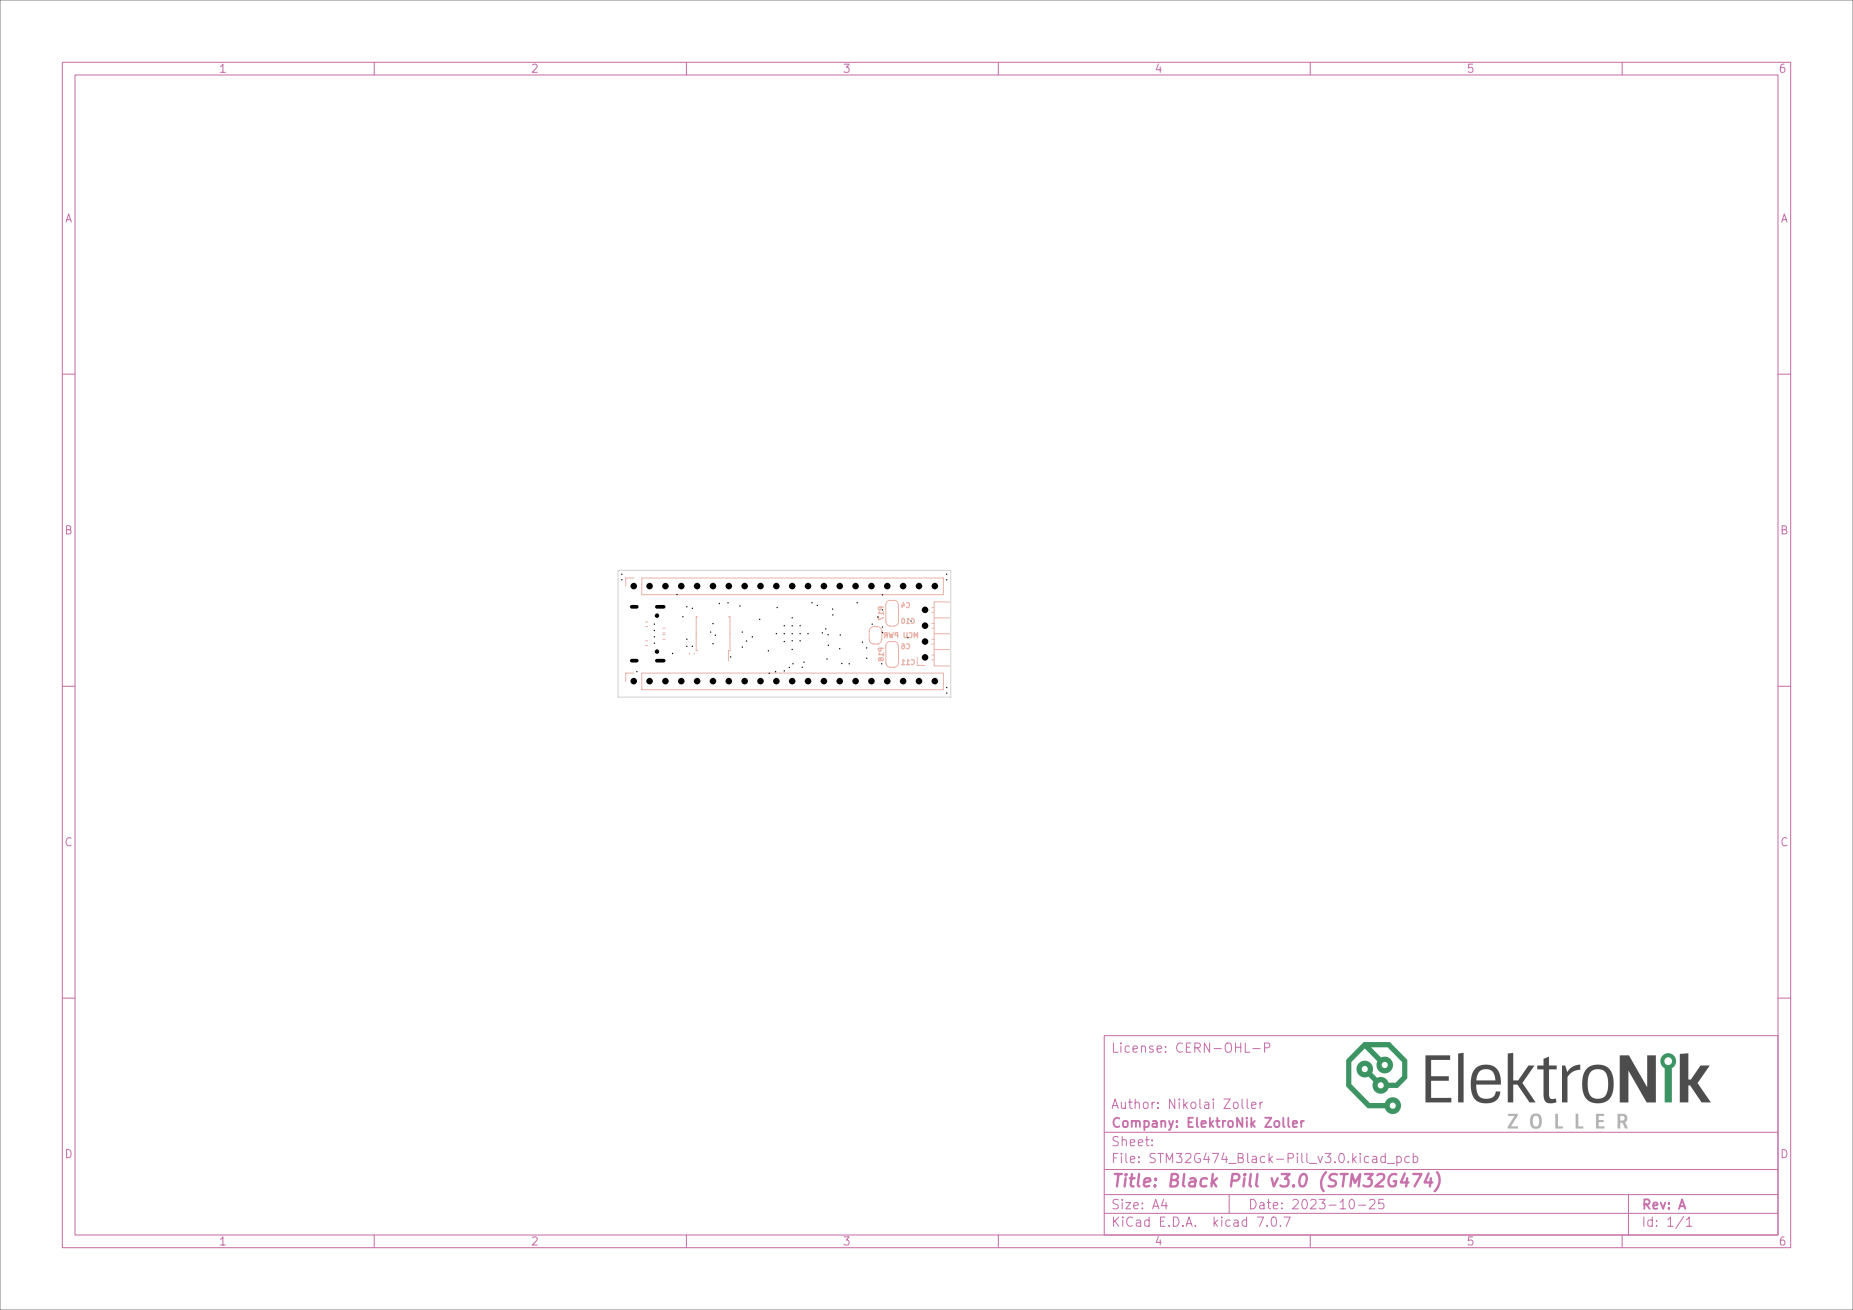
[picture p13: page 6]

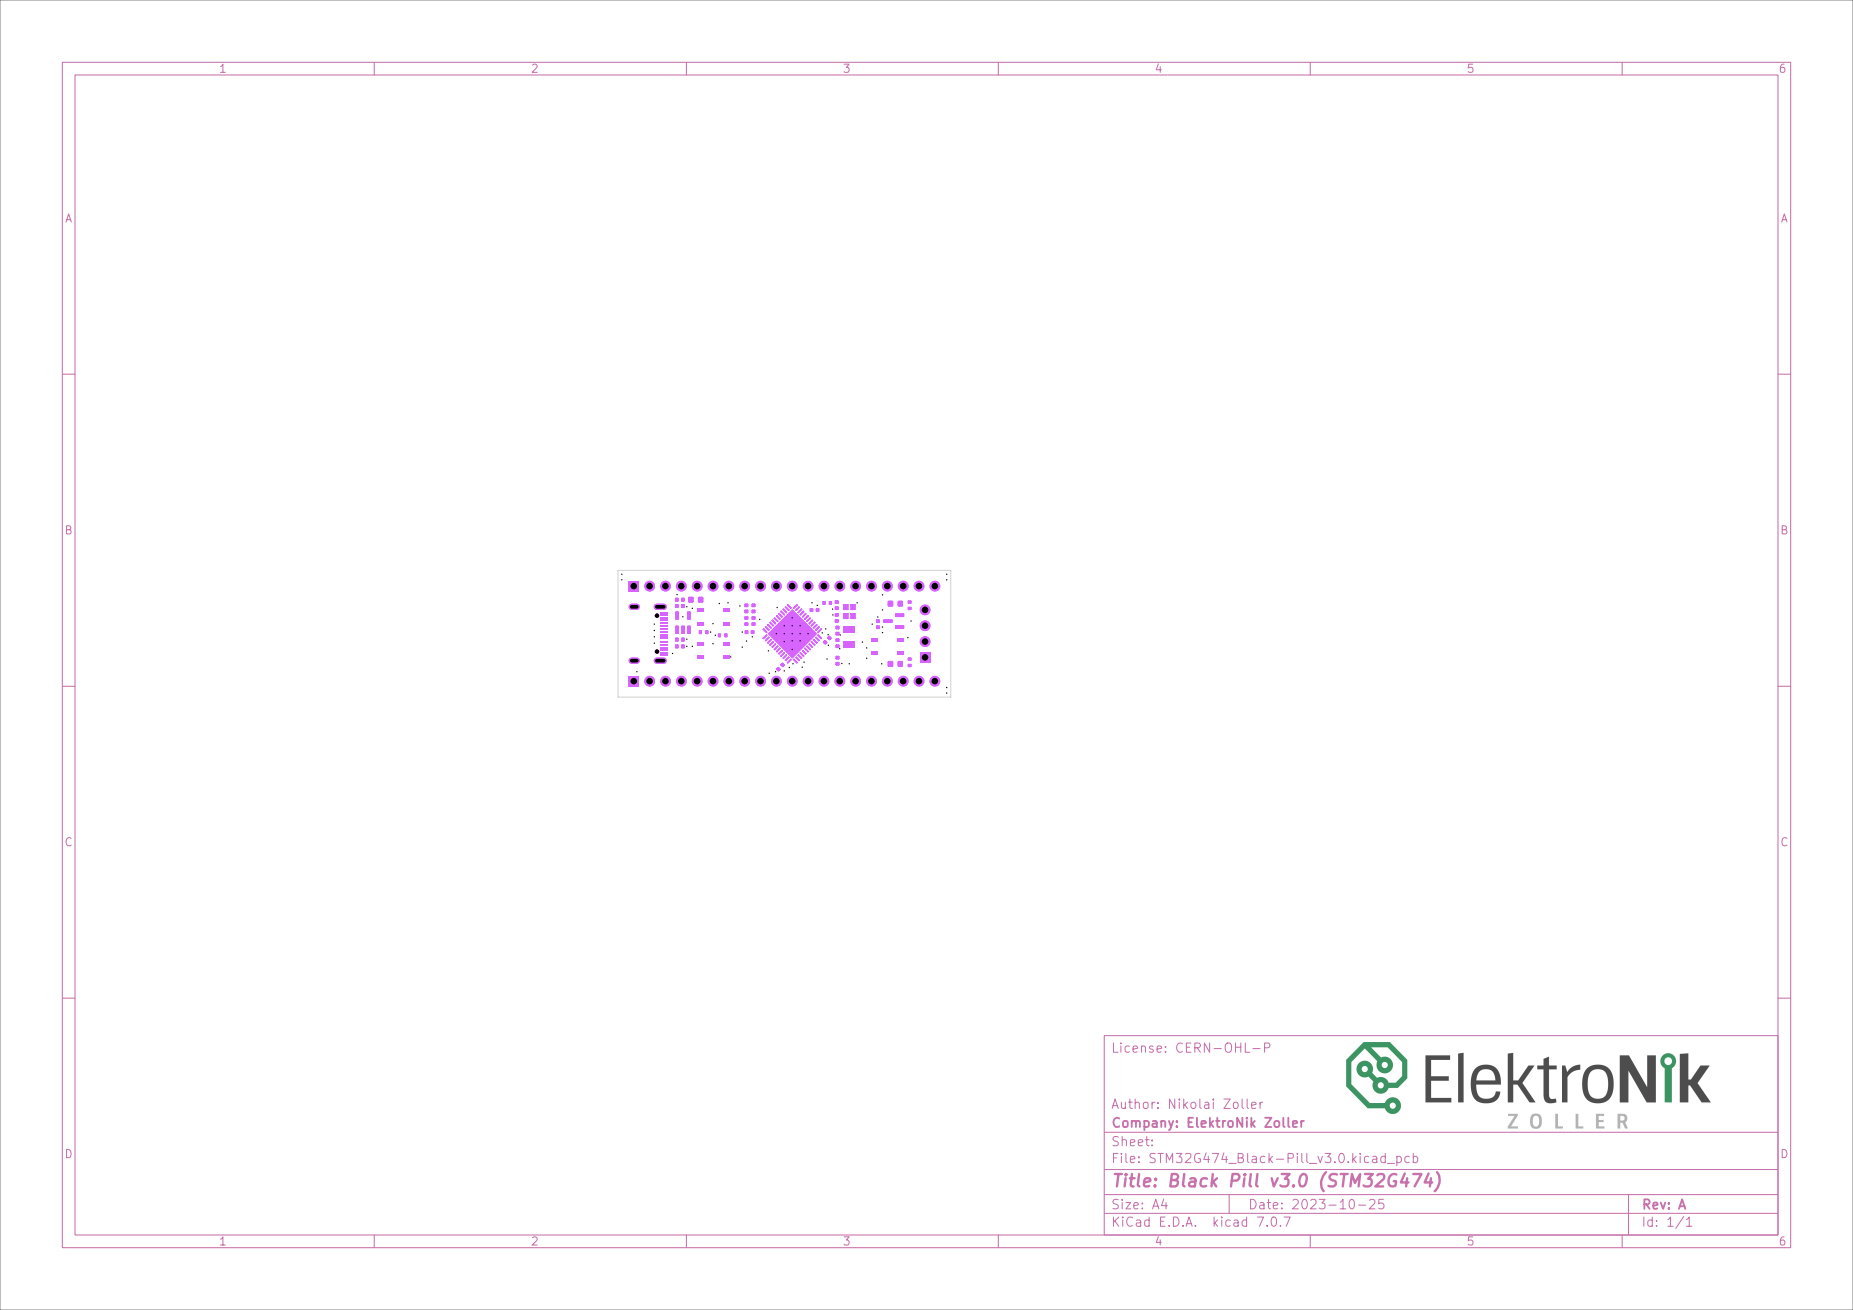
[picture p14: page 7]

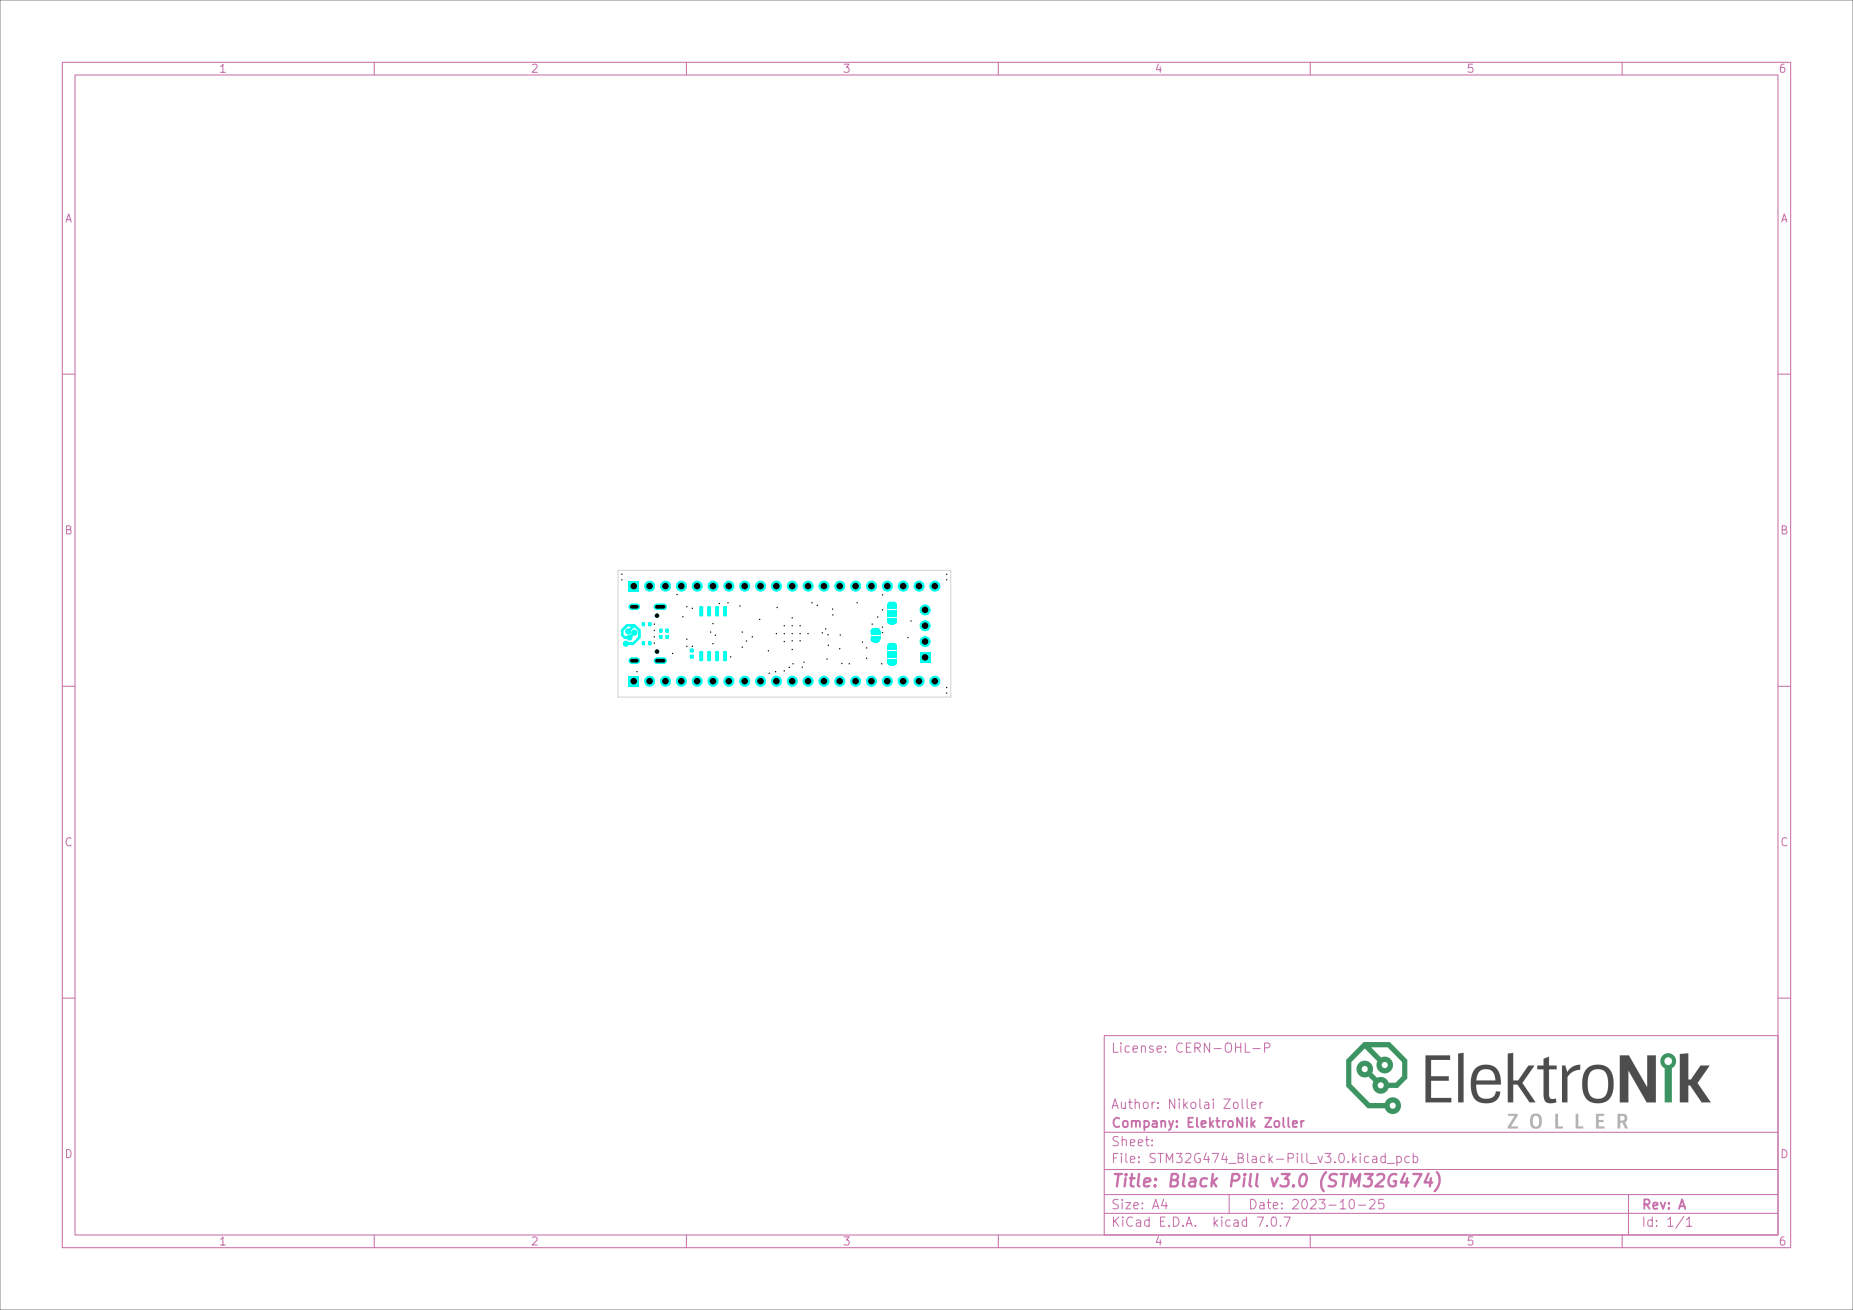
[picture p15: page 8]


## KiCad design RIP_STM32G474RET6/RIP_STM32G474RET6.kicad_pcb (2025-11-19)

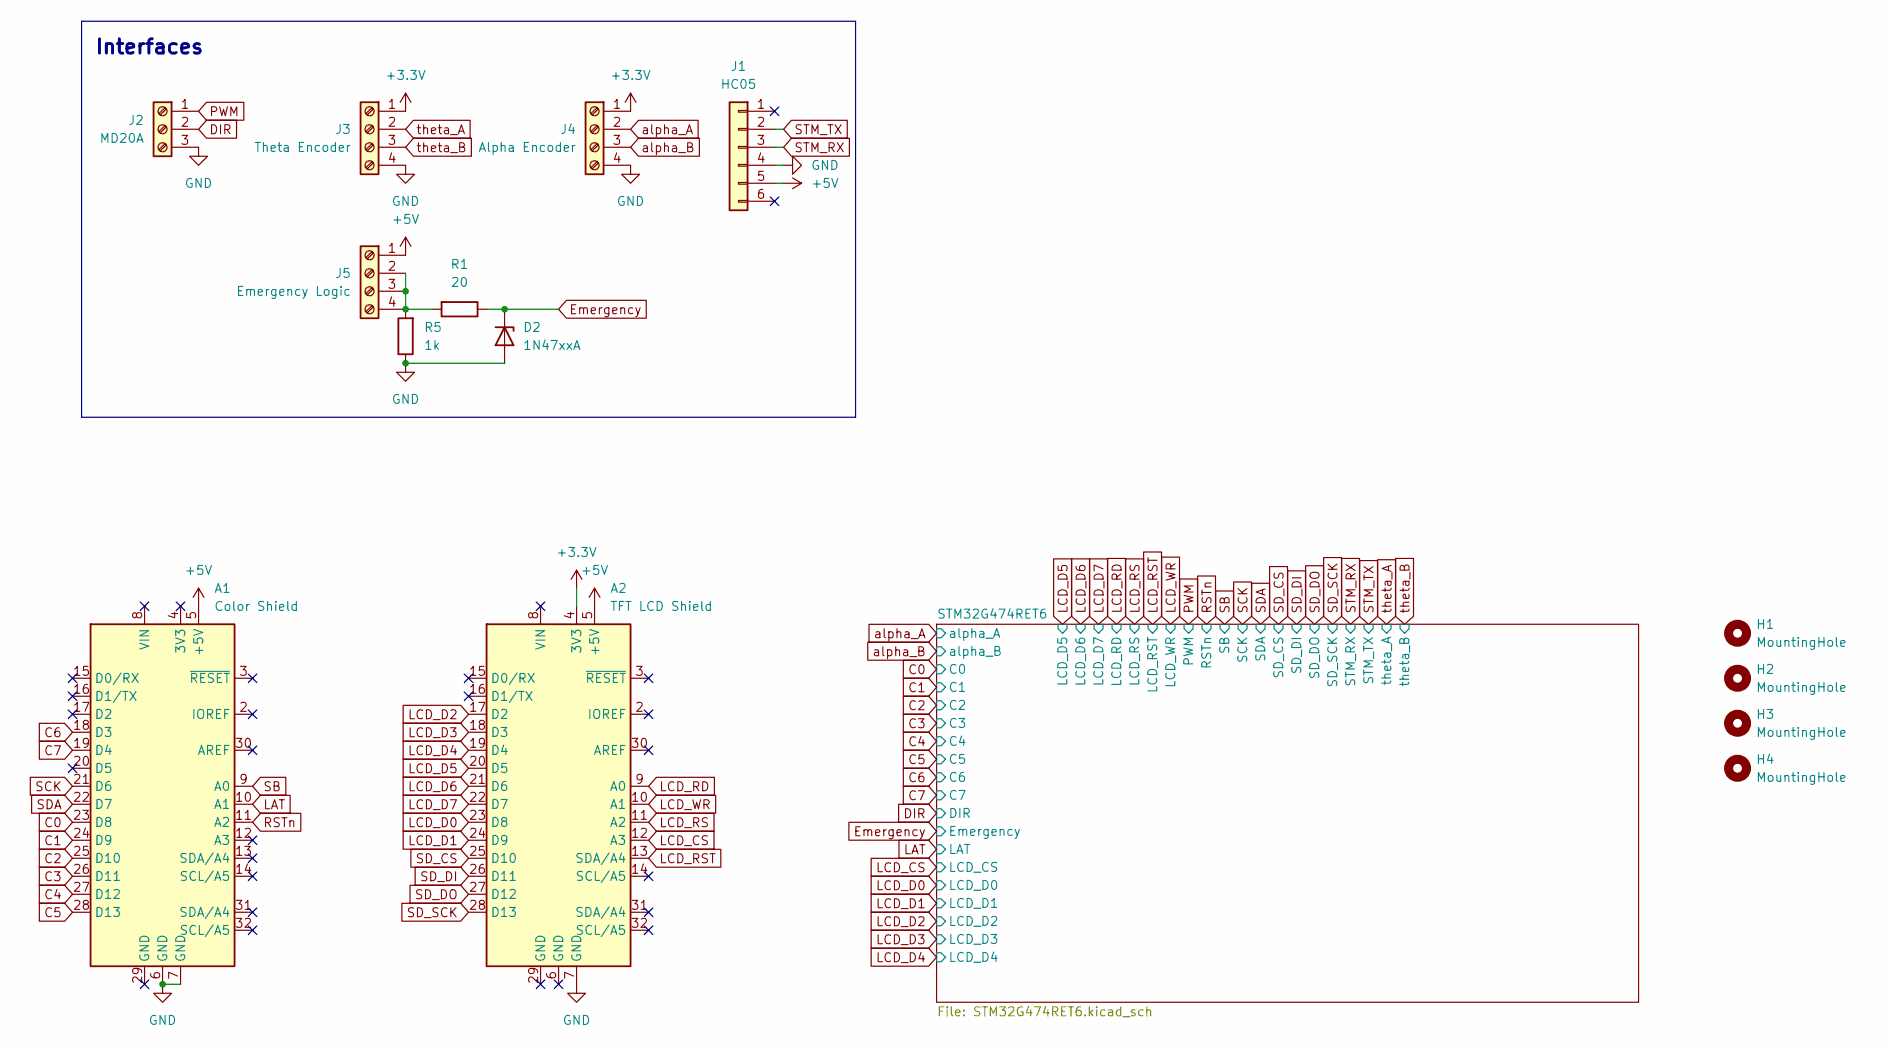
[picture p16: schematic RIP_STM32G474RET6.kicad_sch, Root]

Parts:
A1: Color Shield; Arduino_UNO_R3
A2: TFT LCD Shield; Arduino_UNO_R3
D2: 1N47xxA; D_DO-41_SOD81_P10.16mm_Horizontal
H1, H2, H3, H4: MountingHole; MountingHole_3mm
J1: HC05; PinSocket_1x06_P2.54mm_Vertical
J2: MD20A; PhoenixContact_MC_1,5_3-G-5.08_1x03_P5.08mm_Horizontal
J3: Theta Encoder; PhoenixContact_MC_1,5_4-G-5.08_1x04_P5.08mm_Horizontal
J4: Alpha Encoder; PhoenixContact_MC_1,5_4-G-5.08_1x04_P5.08mm_Horizontal
J5: Emergency Logic; PhoenixContact_MC_1,5_4-G-5.08_1x04_P5.08mm_Horizontal
R1: 20; R_Axial_DIN0309_L9.0mm_D3.2mm_P12.70mm_Horizontal
R5: 1k; R_Axial_DIN0309_L9.0mm_D3.2mm_P12.70mm_Horizontal

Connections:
+5V: A1.5 (+5V), A2.5 (+5V), J1.5, J5.1; also elsewhere on the board
C0: A1.23 (D8); also elsewhere on the board
C1: A1.24 (D9); also elsewhere on the board
C2: A1.25 (D10); also elsewhere on the board
C3: A1.26 (D11); also elsewhere on the board
C4: A1.27 (D12); also elsewhere on the board
C5: A1.28 (D13); also elsewhere on the board
C6: A1.18 (D3); also elsewhere on the board
C7: A1.19 (D4); also elsewhere on the board
DIR: J2.2; also elsewhere on the board
Emergency: D2.1 (K), R1.1; also elsewhere on the board
LAT: A1.10 (A1); also elsewhere on the board
LCD_CS: A2.12 (A3); also elsewhere on the board
LCD_D0: A2.23 (D8); also elsewhere on the board
LCD_D1: A2.24 (D9); also elsewhere on the board
LCD_D2: A2.17 (D2); also elsewhere on the board
LCD_D3: A2.18 (D3); also elsewhere on the board
LCD_D4: A2.19 (D4); also elsewhere on the board
LCD_D5: A2.20 (D5); also elsewhere on the board
LCD_D6: A2.21 (D6); also elsewhere on the board
LCD_D7: A2.22 (D7); also elsewhere on the board
LCD_RD: A2.9 (A0); also elsewhere on the board
LCD_RS: A2.11 (A2); also elsewhere on the board
LCD_RST: A2.13 (SDA/A4); also elsewhere on the board
LCD_WR: A2.10 (A1); also elsewhere on the board
unnamed: J5.2, J5.3, J5.4, R1.2, R5.2
PWM: J2.1; also elsewhere on the board
RSTn: A1.11 (A2); also elsewhere on the board
SB: A1.9 (A0); also elsewhere on the board
SCK: A1.21 (D6); also elsewhere on the board
SDA: A1.22 (D7); also elsewhere on the board
SD_CS: A2.25 (D10); also elsewhere on the board
SD_DI: A2.26 (D11); also elsewhere on the board
SD_DO: A2.27 (D12); also elsewhere on the board
SD_SCK: A2.28 (D13); also elsewhere on the board
STM_RX: J1.3; also elsewhere on the board
STM_TX: J1.2; also elsewhere on the board
VDD: A2.4 (3V3), J3.1, J4.1; also elsewhere on the board
VSSA: A1.6 (GND), A1.7 (GND), A2.7 (GND), D2.2 (A), J1.4, J2.3, J3.4, J4.4, R5.1; also elsewhere on the board
alpha_A: J4.2; also elsewhere on the board
alpha_B: J4.3; also elsewhere on the board
theta_A: J3.2; also elsewhere on the board
theta_B: J3.3; also elsewhere on the board

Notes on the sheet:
Interfaces

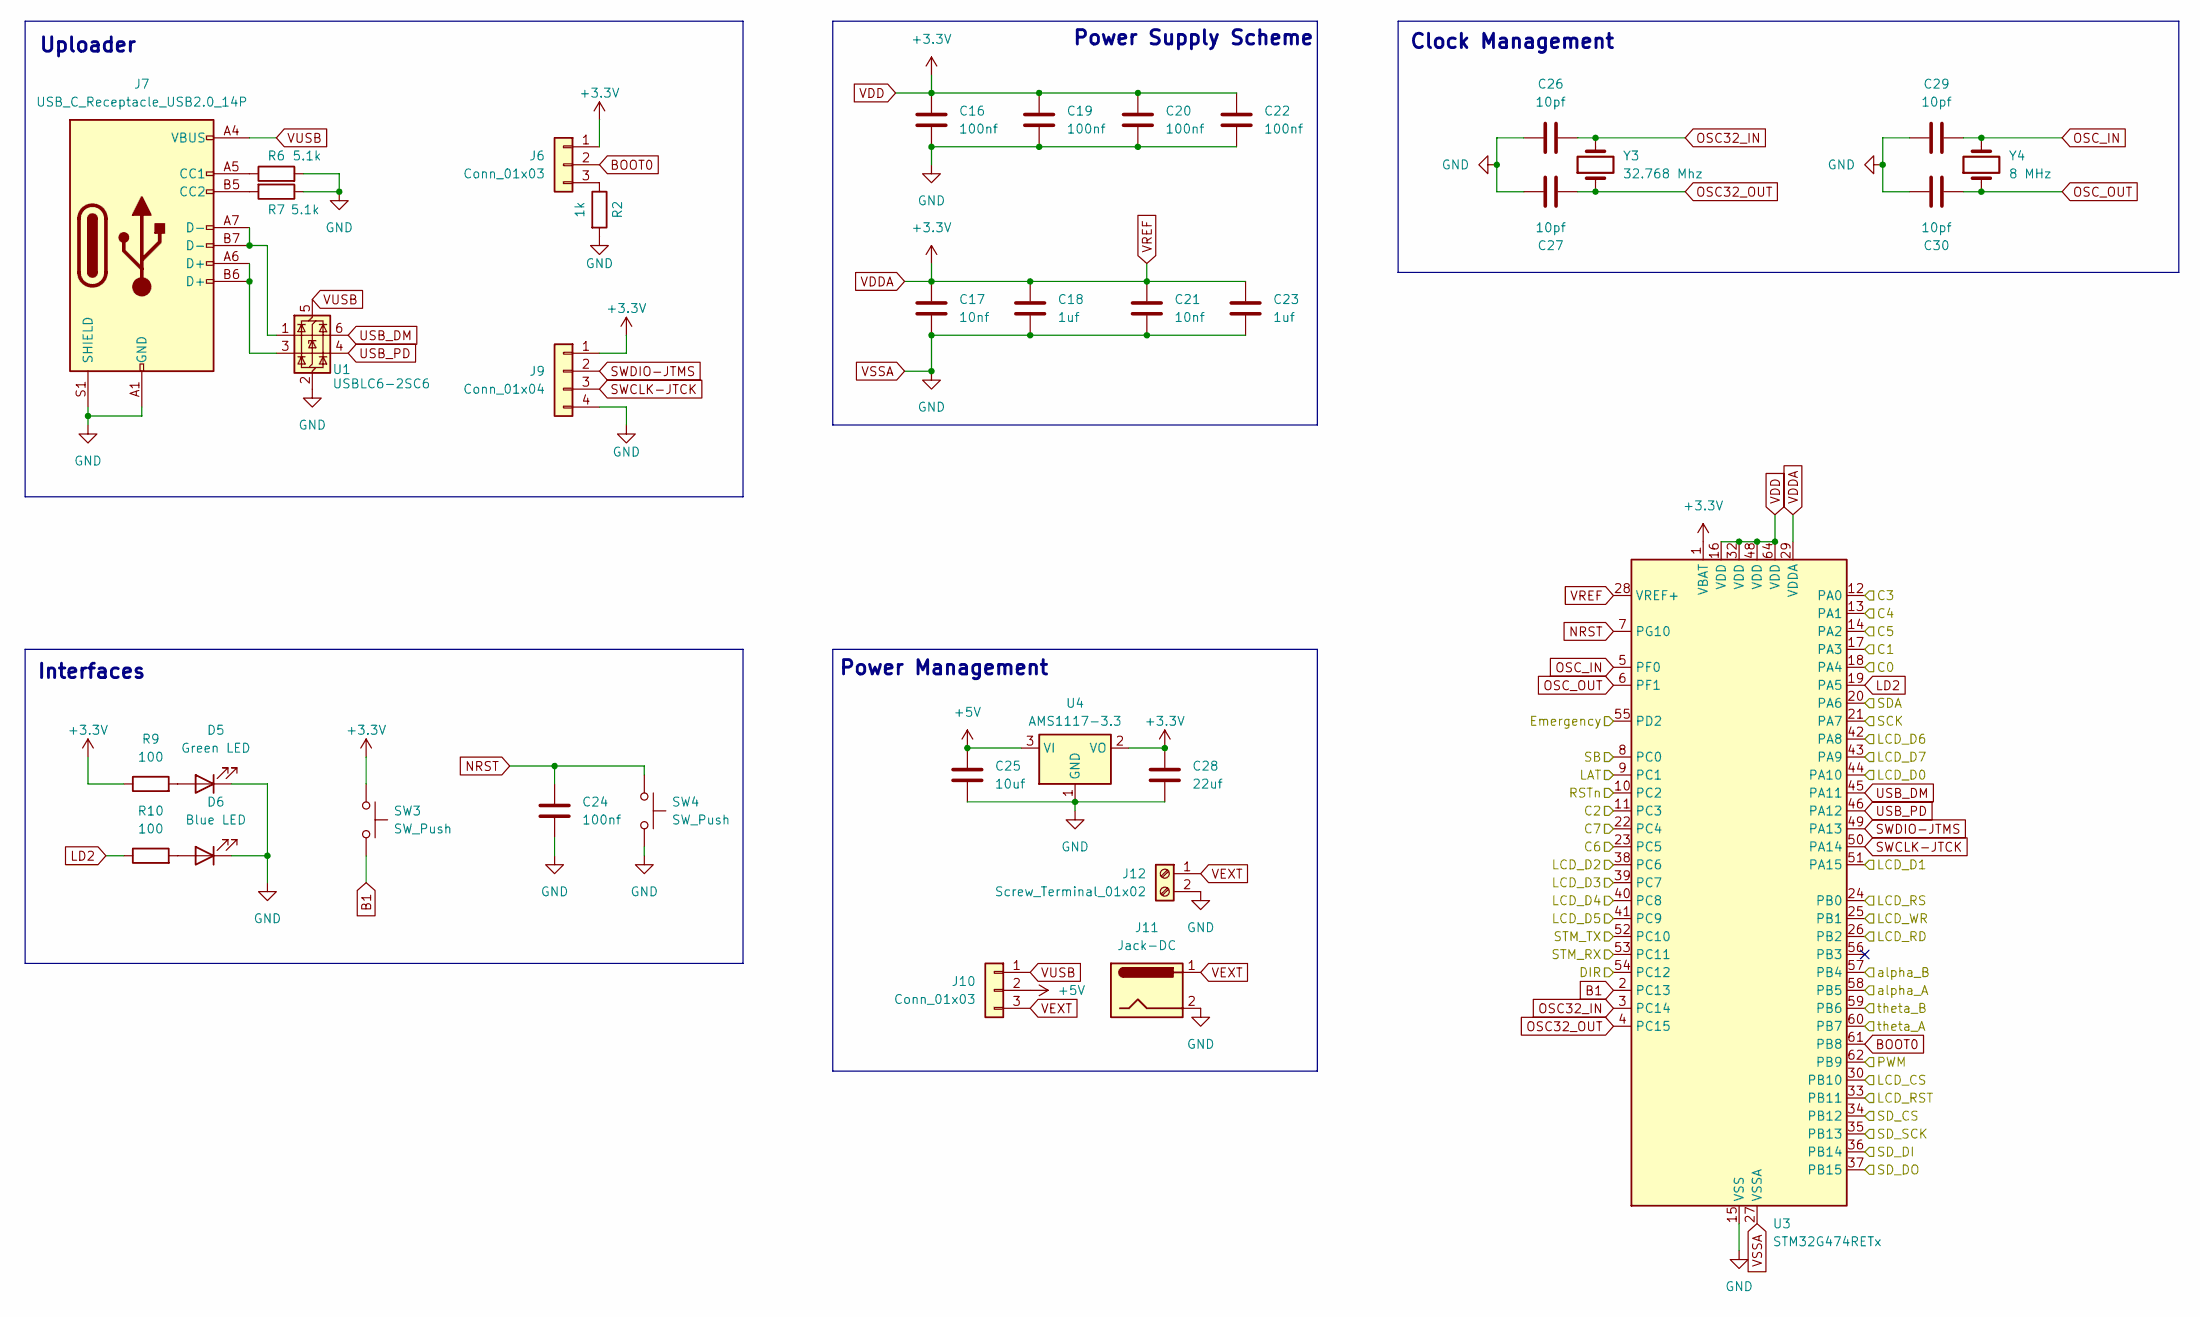
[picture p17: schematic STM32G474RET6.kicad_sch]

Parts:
C16, C19, C20, C22, C24: 100nf; C_0402_1005Metric
C17, C21: 10nf; C_0402_1005Metric
C18, C23: 1uf; C_0402_1005Metric
C25: 10uf; C_0402_1005Metric
C26, C27, C29, C30: 10pf; C_0402_1005Metric
C28: 22uf; C_0402_1005Metric
D5: Green LED; LED_0603_1608Metric
D6: Blue LED; LED_0603_1608Metric
J6, J10: Conn_01x03; PinHeader_1x03_P2.54mm_Vertical
J7: USB_C_Receptacle_USB2.0_14P; USB_C_Receptacle_GCT_USB4105-xx-A_16P_TopMnt_Horizontal
J9: Conn_01x04; PinHeader_1x04_P2.54mm_Vertical
J11: Jack-DC; BarrelJack_Horizontal
J12: Screw_Terminal_01x02; PhoenixContact_MC_1,5_2-G-5.08_1x02_P5.08mm_Horizontal
R2: 1k; R_0402_1005Metric
R6, R7: 5.1k; R_0402_1005Metric
R9, R10: 100; R_0402_1005Metric
SW3, SW4: SW_Push; SW_SPST_PTS810
U1: USBLC6-2SC6; SOT-23-6
U3: STM32G474RETx; LQFP-64_10x10mm_P0.5mm
U4: AMS1117-3.3; SOT-223-3_TabPin2
Y3: 32.768 Mhz; Crystal_SMD_MicroCrystal_CC7V-T1A-2Pin_3.2x1.5mm
Y4: 8 MHz; Crystal_SMD_MicroCrystal_CC7V-T1A-2Pin_3.2x1.5mm

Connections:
+5V: C25.1, J10.2, U4.3 (VI); also elsewhere on the board
B1: SW3.2, U3.2 (PC13)
BOOT0: J6.2, U3.61 (PB8)
C0: U3.18 (PA4); also elsewhere on the board
C1: U3.17 (PA3); also elsewhere on the board
C2: U3.11 (PC3); also elsewhere on the board
C3: U3.12 (PA0); also elsewhere on the board
C4: U3.13 (PA1); also elsewhere on the board
C5: U3.14 (PA2); also elsewhere on the board
C6: U3.23 (PC5); also elsewhere on the board
C7: U3.22 (PC4); also elsewhere on the board
DIR: U3.54 (PC12); also elsewhere on the board
Emergency: U3.55 (PD2); also elsewhere on the board
LAT: U3.9 (PC1); also elsewhere on the board
LCD_CS: U3.30 (PB10); also elsewhere on the board
LCD_D0: U3.44 (PA10); also elsewhere on the board
LCD_D1: U3.51 (PA15); also elsewhere on the board
LCD_D2: U3.38 (PC6); also elsewhere on the board
LCD_D3: U3.39 (PC7); also elsewhere on the board
LCD_D4: U3.40 (PC8); also elsewhere on the board
LCD_D5: U3.41 (PC9); also elsewhere on the board
LCD_D6: U3.42 (PA8); also elsewhere on the board
LCD_D7: U3.43 (PA9); also elsewhere on the board
LCD_RD: U3.26 (PB2); also elsewhere on the board
LCD_RS: U3.24 (PB0); also elsewhere on the board
LCD_RST: U3.33 (PB11); also elsewhere on the board
LCD_WR: U3.25 (PB1); also elsewhere on the board
LD2: R10.1, U3.19 (PA5)
NRST: C24.1, SW4.1, U3.7 (PG10)
unnamed: D5.2 (A), R9.2
unnamed: D6.2 (A), R10.2
unnamed: J6.3, R2.1
unnamed: J7.A5 (CC1), R6.1
unnamed: J7.B5 (CC2), R7.2
unnamed: J7.A6 (D+), J7.B6 (D+), U1.3 (I/O2)
unnamed: J7.A7 (D-), J7.B7 (D-), U1.1 (I/O1)
OSC32_IN: C26.1, U3.3 (PC14), Y3.2
OSC32_OUT: C27.2, U3.4 (PC15), Y3.1
OSC_IN: C29.1, U3.5 (PF0), Y4.2
OSC_OUT: C30.2, U3.6 (PF1), Y4.1
PWM: U3.62 (PB9); also elsewhere on the board
RSTn: U3.10 (PC2); also elsewhere on the board
SB: U3.8 (PC0); also elsewhere on the board
SCK: U3.21 (PA7); also elsewhere on the board
SDA: U3.20 (PA6); also elsewhere on the board
SD_CS: U3.34 (PB12); also elsewhere on the board
SD_DI: U3.36 (PB14); also elsewhere on the board
SD_DO: U3.37 (PB15); also elsewhere on the board
SD_SCK: U3.35 (PB13); also elsewhere on the board
STM_RX: U3.53 (PC11); also elsewhere on the board
STM_TX: U3.52 (PC10); also elsewhere on the board
SWCLK-JTCK: J9.3, U3.50 (PA14)
SWDIO-JTMS: J9.2, U3.49 (PA13)
USB_DM: U1.6 (I/O1), U3.45 (PA11)
USB_PD: U1.4 (I/O2), U3.46 (PA12)
VDD: C16.1, C17.1, C18.1, C19.1, C20.1, C21.1, C22.1, C23.1, C28.1, J6.1, J9.1, R9.1, SW3.1, U3.1 (VBAT), U3.16 (VDD), U3.28 (VREF+), U3.29 (VDDA), U3.32 (VDD), U3.48 (VDD), U3.64 (VDD), U4.2 (VO); also elsewhere on the board
VEXT: J10.3, J11.1, J12.1
VSSA: C16.2, C17.2, C18.2, C19.2, C20.2, C21.2, C22.2, C23.2, C24.2, C25.2, C26.2, C27.1, C28.2, C29.2, C30.1, D5.1 (K), D6.1 (K), J7.A1 (GND), J7.A12 (GND), J7.B1 (GND), J7.B12 (GND), J7.S1 (SHIELD), J9.4, J11.2, J12.2, R2.2, R6.2, R7.1, SW4.2, U1.2 (GND), U3.15 (VSS), U3.27 (VSSA), U3.31 (VSS), U3.47 (VSS), U3.63 (VSS), U4.1 (GND); also elsewhere on the board
VUSB: J7.A4 (VBUS), J7.A9 (VBUS), J7.B4 (VBUS), J7.B9 (VBUS), J10.1, U1.5 (VBUS)
alpha_A: U3.58 (PB5); also elsewhere on the board
alpha_B: U3.57 (PB4); also elsewhere on the board
theta_A: U3.60 (PB7); also elsewhere on the board
theta_B: U3.59 (PB6); also elsewhere on the board

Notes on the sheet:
Interfaces
Clock Management
Uploader
Power Management
Power Supply Scheme

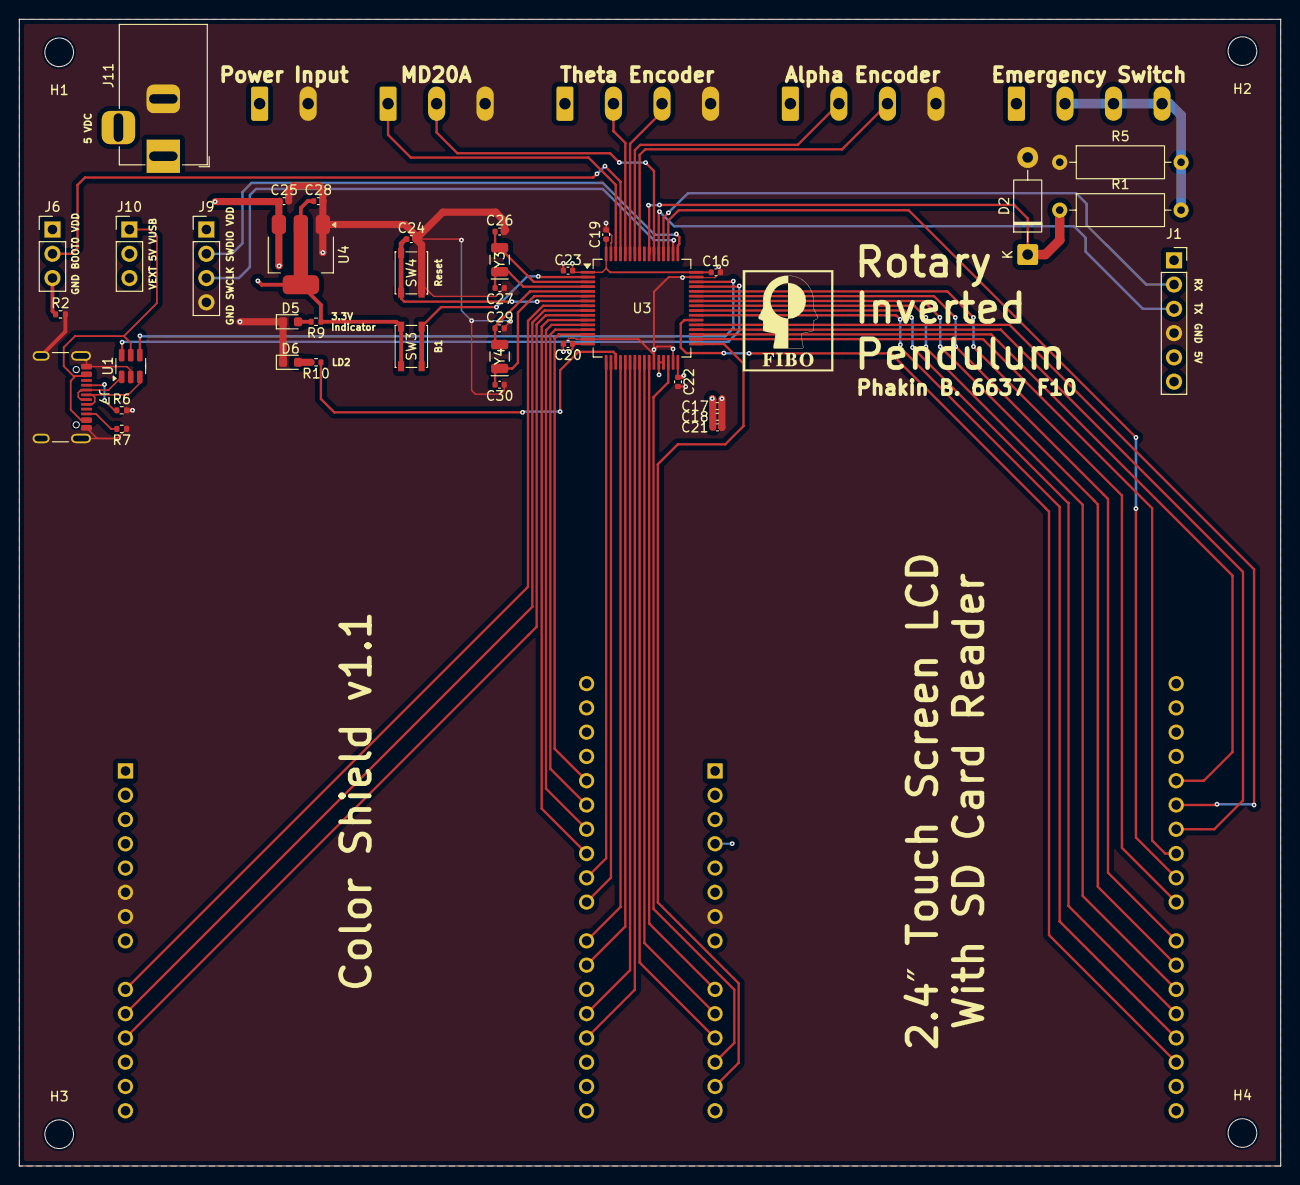
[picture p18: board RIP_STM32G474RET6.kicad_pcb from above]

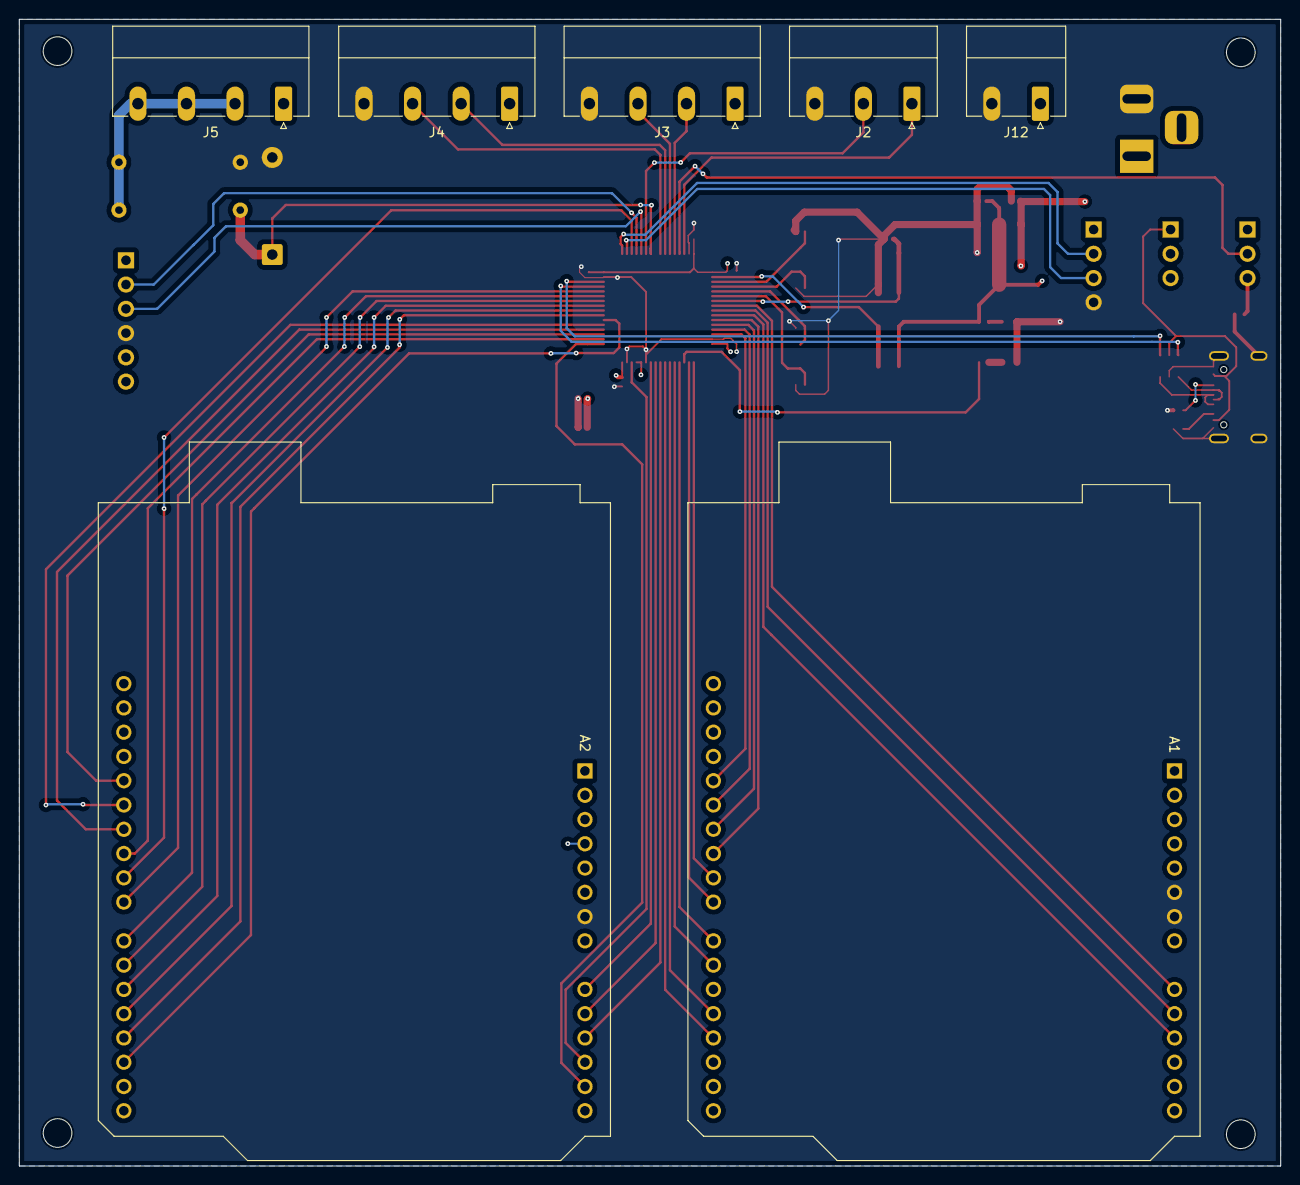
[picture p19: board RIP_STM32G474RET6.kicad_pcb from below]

Board: 4 copper layers, 132.0 x 120.0 mm, 49 parts (7 on the bottom side), 64 nets.

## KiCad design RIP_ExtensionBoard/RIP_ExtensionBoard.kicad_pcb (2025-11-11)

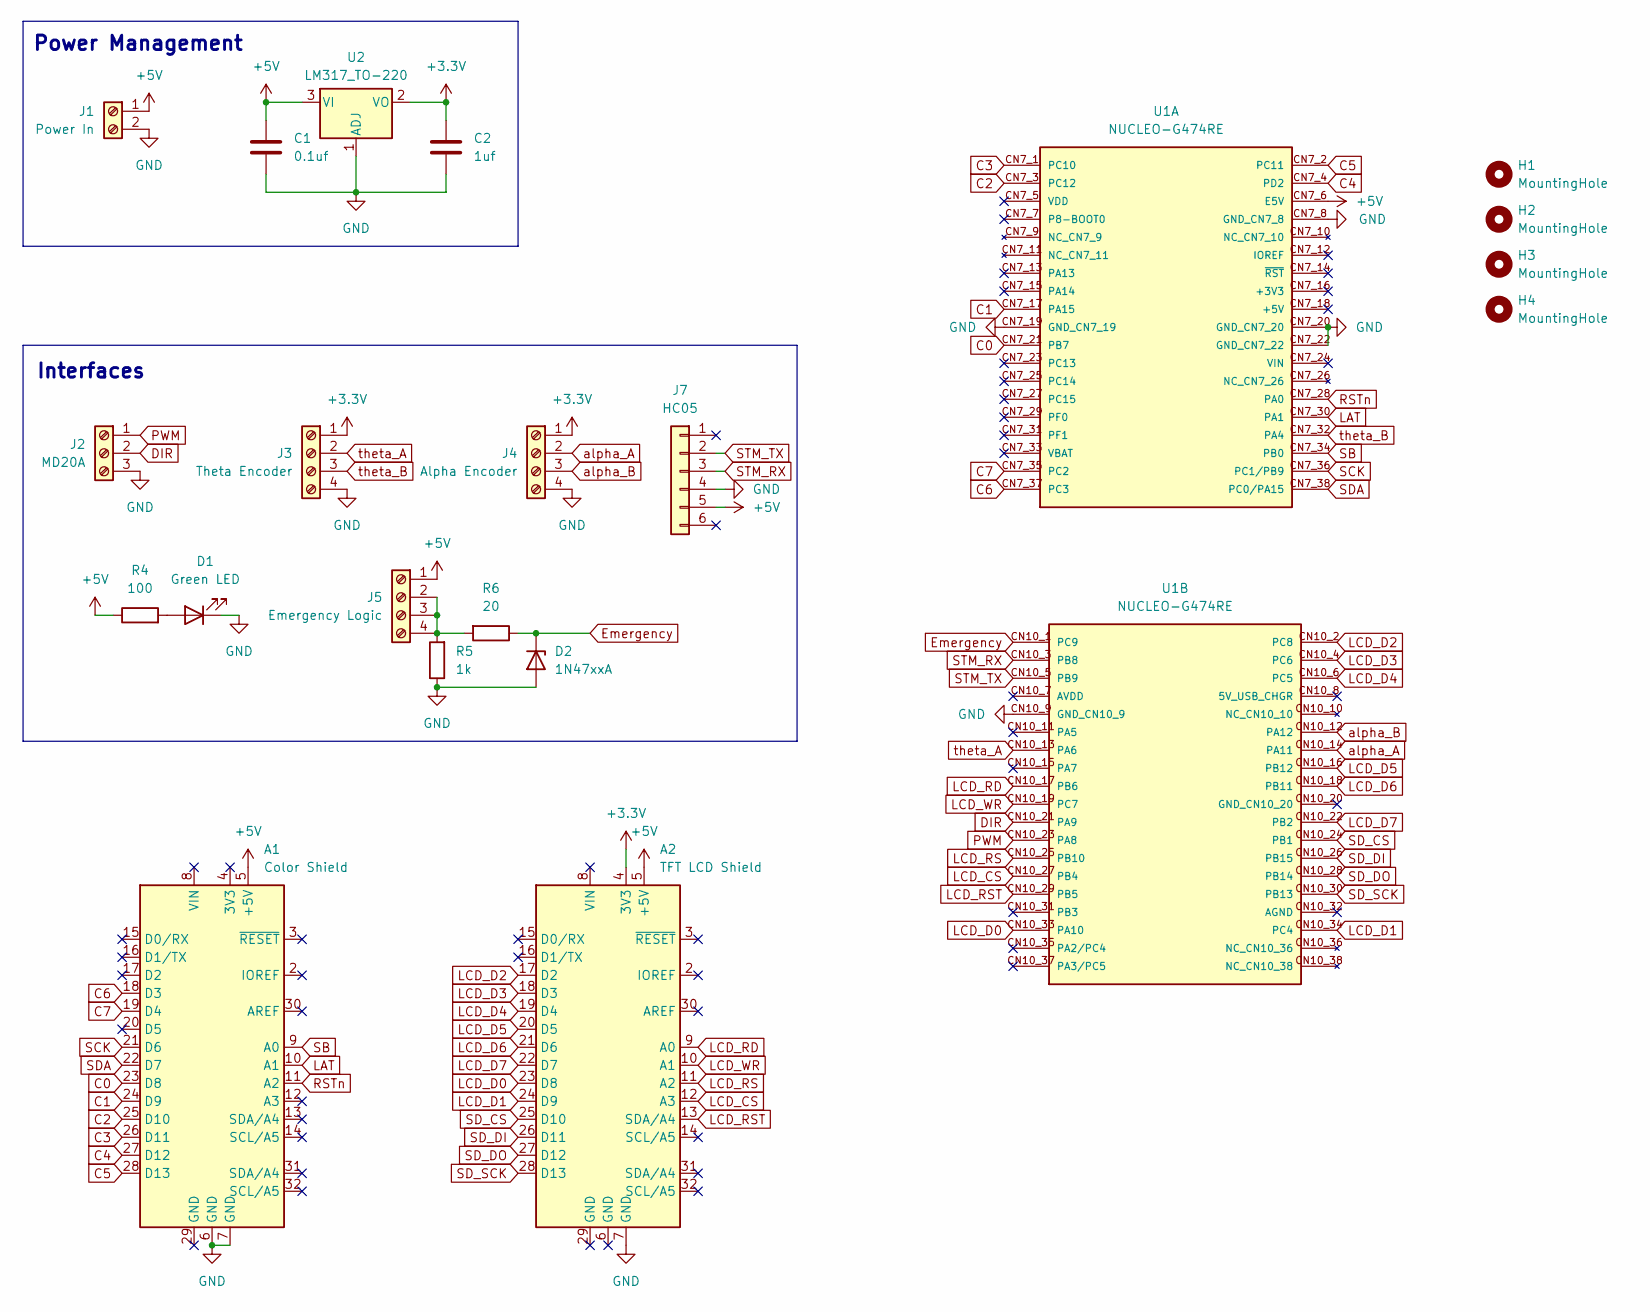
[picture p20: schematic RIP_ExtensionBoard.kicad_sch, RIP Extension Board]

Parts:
A1: Color Shield; Arduino_UNO_R3
A2: TFT LCD Shield; Arduino_UNO_R3
C1: 0.1uf; C_Disc_D5.0mm_W2.5mm_P2.50mm
C2: 1uf; C_Disc_D5.0mm_W2.5mm_P2.50mm
D1: Green LED; LED_D3.0mm
D2: 1N47xxA; D_DO-41_SOD81_P10.16mm_Horizontal
H1, H2, H3, H4: MountingHole; MountingHole_3mm
J1: Power In; PhoenixContact_MC_1,5_2-G-5.08_1x02_P5.08mm_Horizontal
J2: MD20A; PhoenixContact_MC_1,5_3-G-5.08_1x03_P5.08mm_Horizontal
J3: Theta Encoder; PhoenixContact_MC_1,5_4-G-5.08_1x04_P5.08mm_Horizontal
J4: Alpha Encoder; PhoenixContact_MC_1,5_4-G-5.08_1x04_P5.08mm_Horizontal
J5: Emergency Logic; PhoenixContact_MC_1,5_4-G-5.08_1x04_P5.08mm_Horizontal
J7: HC05; PinSocket_1x06_P2.54mm_Vertical
R4: 100; R_Axial_DIN0309_L9.0mm_D3.2mm_P12.70mm_Horizontal
R5: 1k; R_Axial_DIN0309_L9.0mm_D3.2mm_P12.70mm_Horizontal
R6: 20; R_Axial_DIN0309_L9.0mm_D3.2mm_P12.70mm_Horizontal
U1: NUCLEO-G474RE; MODULE_NUCLEO-G474RE; PARTREV 17
U2: LM317_TO-220; TO-220-3_Vertical

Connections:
+3.3V: A2.4 (3V3), C2.1, J3.1, J4.1, U2.2 (VO)
+5V: A1.5 (+5V), A2.5 (+5V), C1.1, J1.1, J5.1, J7.5, R4.1, U1.CN7_6 (E5V), U2.3 (VI)
C0: A1.23 (D8), U1.CN7_21 (PB7)
C1: A1.24 (D9), U1.CN7_17 (PA15)
C2: A1.25 (D10), U1.CN7_3 (PC12)
C3: A1.26 (D11), U1.CN7_1 (PC10)
C4: A1.27 (D12), U1.CN7_4 (PD2)
C5: A1.28 (D13), U1.CN7_2 (PC11)
C6: A1.18 (D3), U1.CN7_37 (PC3)
C7: A1.19 (D4), U1.CN7_35 (PC2)
DIR: J2.2, U1.CN10_21 (PA9)
Emergency: D2.1 (K), R6.1, U1.CN10_1 (PC9)
GND: A1.6 (GND), A1.7 (GND), A2.7 (GND), C1.2, C2.2, D1.1 (K), D2.2 (A), J1.2, J2.3, J3.4, J4.4, J7.4, R5.1, U1.CN7_8 (GND_CN7_8), U1.CN7_19 (GND_CN7_19), U1.CN7_20 (GND_CN7_20), U1.CN7_22 (GND_CN7_22), U1.CN10_9 (GND_CN10_9), U2.1 (ADJ)
LAT: A1.10 (A1), U1.CN7_30 (PA1)
LCD_CS: A2.12 (A3), U1.CN10_27 (PB4)
LCD_D0: A2.23 (D8), U1.CN10_33 (PA10)
LCD_D1: A2.24 (D9), U1.CN10_34 (PC4)
LCD_D2: A2.17 (D2), U1.CN10_2 (PC8)
LCD_D3: A2.18 (D3), U1.CN10_4 (PC6)
LCD_D4: A2.19 (D4), U1.CN10_6 (PC5)
LCD_D5: A2.20 (D5), U1.CN10_16 (PB12)
LCD_D6: A2.21 (D6), U1.CN10_18 (PB11)
LCD_D7: A2.22 (D7), U1.CN10_22 (PB2)
LCD_RD: A2.9 (A0), U1.CN10_17 (PB6)
LCD_RS: A2.11 (A2), U1.CN10_25 (PB10)
LCD_RST: A2.13 (SDA/A4), U1.CN10_29 (PB5)
LCD_WR: A2.10 (A1), U1.CN10_19 (PC7)
unnamed: D1.2 (A), R4.2
unnamed: J5.2, J5.3, J5.4, R5.2, R6.2
PWM: J2.1, U1.CN10_23 (PA8)
RSTn: A1.11 (A2), U1.CN7_28 (PA0)
SB: A1.9 (A0), U1.CN7_34 (PB0)
SCK: A1.21 (D6), U1.CN7_36 (PC1/PB9)
SDA: A1.22 (D7), U1.CN7_38 (PC0/PA15)
SD_CS: A2.25 (D10), U1.CN10_24 (PB1)
SD_DI: A2.26 (D11), U1.CN10_26 (PB15)
SD_DO: A2.27 (D12), U1.CN10_28 (PB14)
SD_SCK: A2.28 (D13), U1.CN10_30 (PB13)
STM_RX: J7.3, U1.CN10_3 (PB8)
STM_TX: J7.2, U1.CN10_5 (PB9)
alpha_A: J4.2, U1.CN10_14 (PA11)
alpha_B: J4.3, U1.CN10_12 (PA12)
theta_A: J3.2, U1.CN10_13 (PA6)
theta_B: J3.3, U1.CN7_32 (PA4)

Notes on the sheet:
Interfaces
Power Management

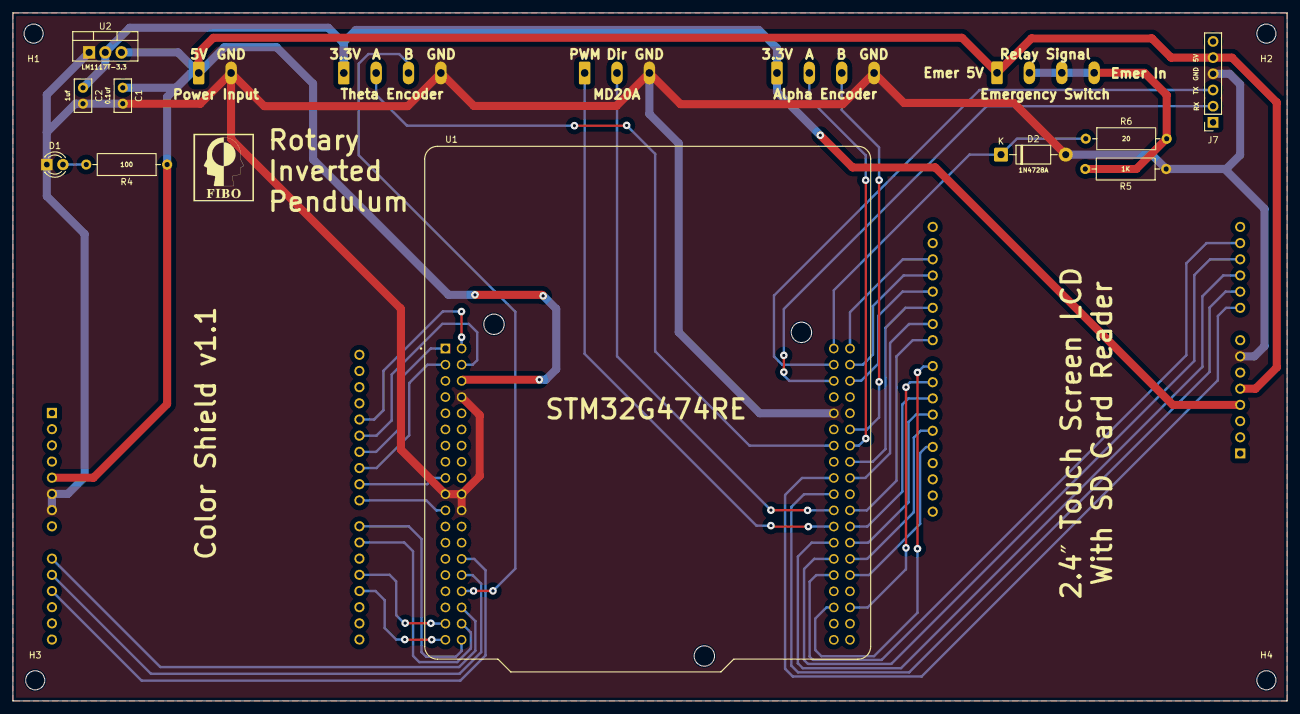
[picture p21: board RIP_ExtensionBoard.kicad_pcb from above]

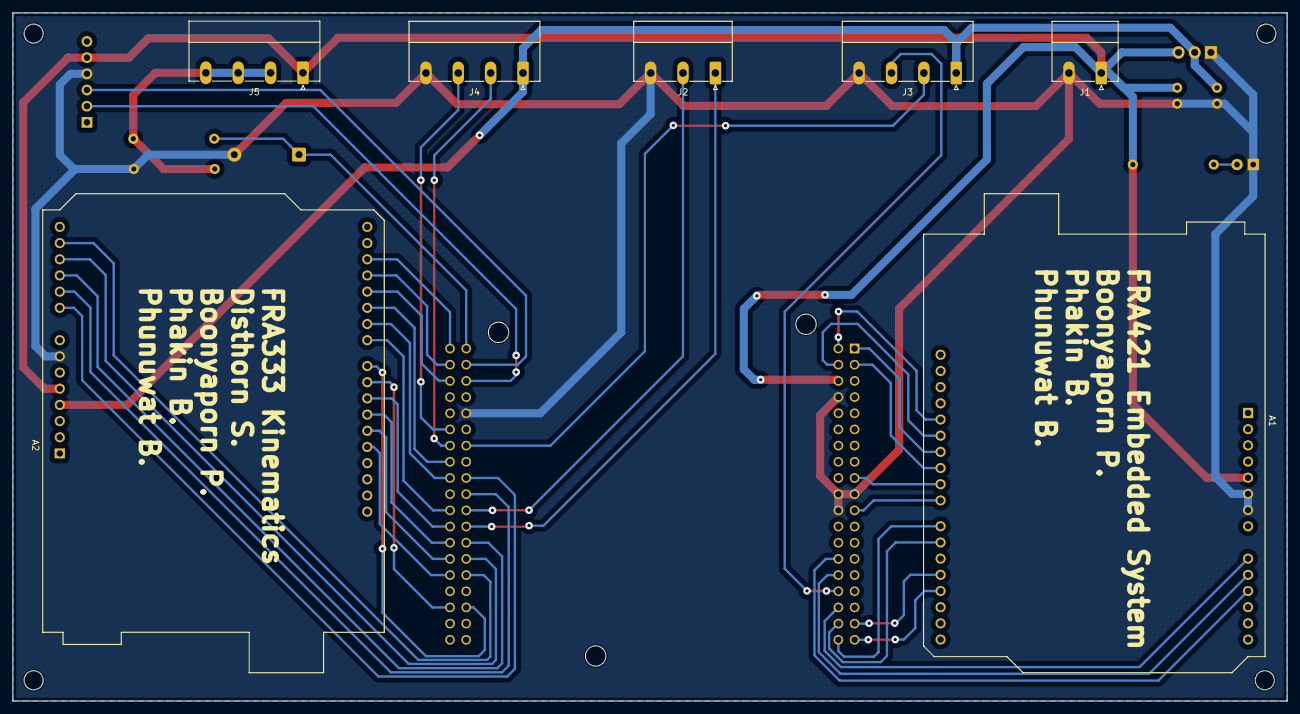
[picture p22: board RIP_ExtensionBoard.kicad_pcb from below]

Board: 2 copper layers, 200.0 x 108.0 mm, 21 parts (7 on the bottom side), 44 nets.

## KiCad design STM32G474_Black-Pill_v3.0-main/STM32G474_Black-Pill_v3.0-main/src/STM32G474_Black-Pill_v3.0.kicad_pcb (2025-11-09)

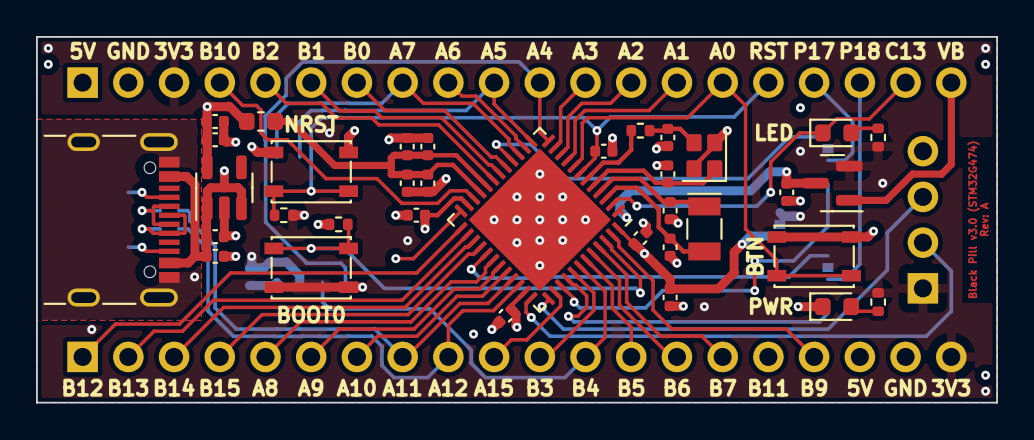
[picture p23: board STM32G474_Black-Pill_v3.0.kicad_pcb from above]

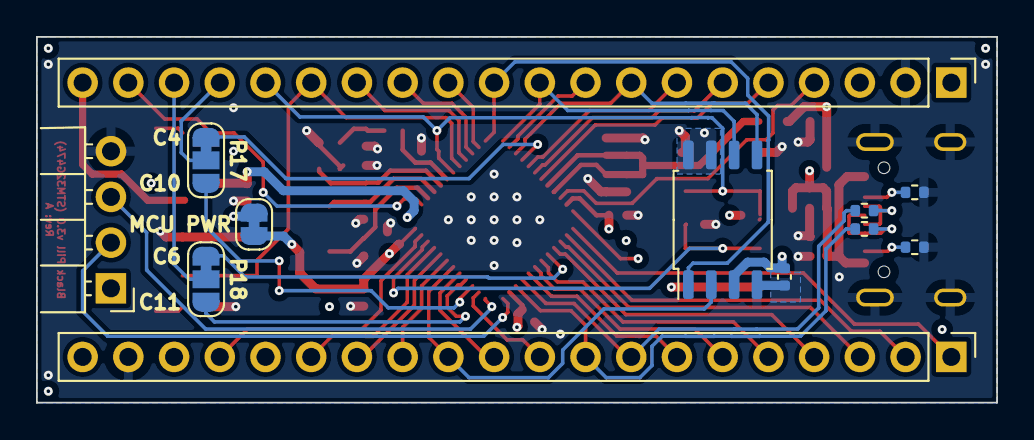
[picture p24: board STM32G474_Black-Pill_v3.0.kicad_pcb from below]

Board: 4 copper layers, 53.3 x 20.3 mm, 47 parts (12 on the bottom side), 58 nets.

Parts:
C101, C104, C108, C109, C110, C112, C114, C115, C119, C120: 100nF; C_0402_1005Metric
C102, C103, C105, C106: 6pF; C_0402_1005Metric
C107: 10µF; C_0402_1005Metric
C113, C116, C117, C118: 1µF; C_0402_1005Metric
D101: red; LED_0603_1608Metric
D102: BAT54C; SOT-23
D103: green; LED_0603_1608Metric
J101: USB_C_Receptacle_USB2.0; USB_C_Receptacle_GCT_USB4105-xx-A_16P_TopMnt_Horizontal
J102, J103: Conn_01x20; PinHeader_1x20_P2.54mm_Vertical
J104: Conn_01x04; PinHeader_1x04_P2.54mm_Horizontal_Board_Edge
JP101, JP102: SolderJumper_3_Bridged12; SolderJumper-3_P1.3mm_Bridged12_RoundedPad1.0x1.5mm_NumberL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
JP103: SolderJumper_2_Bridged; SolderJumper-2_P1.3mm_Bridged_RoundedPad1.0x1.5mm
L101: 10µH; L_0603_1608Metric
R101, R102: 5.1k; R_0402_1005Metric
R103, R108: 10k; R_0402_1005Metric
R104, R105: 10R; R_0402_1005Metric
R106: 0R; R_0402_1005Metric
R107, R109: 100R; R_0402_1005Metric
SW101, SW102, SW103: SW_Push; SW_SPST_PTS810
U101: W25Q32JVSS; SOIC-8_5.23x5.23mm_P1.27mm
U102: STM32G474CEUx; QFN-48-1EP_7x7mm_P0.5mm_EP5.6x5.6mm
U103: AP7343xx; SOT-23-5
Y101: 24MHz; Crystal_SMD_SeikoEpson_FA128-4Pin_2.0x1.6mm
Y102: 32.768kHz; Crystal_SMD_MicroCrystal_CC7V-T1A-2Pin_3.2x1.5mm

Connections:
+3.3V: C101.1, C115.1, C116.1, D102.2, J102.20, J103.3, J104.1, JP103.2 (B), L101.1, R103.1, R107.1, R109.1, SW102.2, U101.3 (IO2), U101.7 (IO3), U101.8 (VCC), U103.5 (OUT)
+5V: C113.1, C114.1, J101.A4 (VBUS), J101.A9 (VBUS), J101.B4 (VBUS), J101.B9 (VBUS), J102.18, J103.1, U103.1 (IN), U103.3 (EN)
/+3.3V_{MCU}: C107.1, C108.1, C109.1, C110.1, JP103.1 (A), U102.23 (VDD), U102.35 (VDD), U102.48 (VDD)
/PA0: J103.15, SW103.2, U102.8 (PA0)
/PA1: J103.14, U102.9 (PA1)
/PA2: J103.13, U102.10 (PA2)
/PA3: J103.12, U102.11 (PA3)
/PA4: J103.11, U101.1 (~CS), U102.12 (PA4)
/PA5: J103.10, U101.6 (CLK), U102.13 (PA5)
/PA6: J103.9, U102.14 (PA6)
/PA7: J103.8, U101.5 (DI(IO0)), U102.15 (PA7)
/PA8: J102.5, U102.30 (PA8)
/PA9: J102.6, U102.31 (PA9)
/PA10: J102.7, U102.32 (PA10)
/PA11: J102.8, R104.2, U102.33 (PA11)
/PA12: J102.9, R105.2, U102.34 (PA12)
/PA15: J102.10, U102.38 (PA15)
/PB0: J103.7, U102.17 (PB0)
/PB1: J103.6, U102.18 (PB1)
/PB2: J103.5, U102.19 (PB2)
/PB3: J102.11, U102.41 (PB3)
/PB4: J102.12, U101.2 (DO(IO1)), U102.42 (PB4)
/PB5: J102.13, U102.43 (PB5)
/PB6: J102.14, U102.44 (PB6)
/PB7: J102.15, U102.45 (PB7)
/PB8: R108.1, SW102.1, U102.46 (PB8)
/PB9: J102.17, U102.47 (PB9)
/PB10: J103.4, U102.22 (PB10)
/PB11: J102.16, U102.24 (PB11)
/PB12: J102.1, U102.25 (PB12)
/PB13: J102.2, U102.26 (PB13)
/PB14: J102.3, U102.27 (PB14)
/PB15: J102.4, U102.28 (PB15)
/PC4: JP101.1 (A), U102.16 (PC4)
/PC6: JP102.1 (A), U102.29 (PC6)
/PC10: JP101.3 (B), U102.39 (PC10)
/PC11: JP102.3 (B), U102.40 (PC11)
/PC13: D103.1 (K), J103.19, U102.2 (PC13)
/PC14: C105.2, U102.3 (PC14), Y102.2
/PC15: C106.2, U102.4 (PC15), Y102.1
/Pin17: J103.17, JP101.2 (C)
/Pin18: J103.18, JP102.2 (C)
/SWCLK: J104.3, U102.37 (PA14)
/SWDIO: J104.2, U102.36 (PA13)
GND: C101.2, C102.1, C103.1, C104.2, C105.1, C106.1, C107.2, C108.2, C109.2, C110.2, C112.2, C113.2, C114.2, C115.2, C116.2, C117.1, C118.1, C119.1, C120.1, D101.1 (K), J101.A1 (GND), J101.A12 (GND), J101.B1 (GND), J101.B12 (GND), J101.S1 (SHIELD), J102.19, J103.2, J104.4, R101.2, R102.2, R108.2, SW101.1, SW103.1, U101.4 (GND), U102.49 (VSS), U103.2 (GND), Y101.2, Y101.4
NRST: C104.1, J103.16, R103.2, SW101.2, U102.7 (PG10)
unnamed: C103.2, R106.2, Y101.3
unnamed: D101.2 (A), R107.2
unnamed: D103.2 (A), R109.2
unnamed: J101.A5 (CC1), R101.1
unnamed: J101.B5 (CC2), R102.1
unnamed: J101.A6 (D+), J101.B6 (D+), R105.1
unnamed: J101.A7 (D-), J101.B7 (D-), R104.1
unnamed: C102.2, U102.5 (PF0), Y101.1
unnamed: R106.1, U102.6 (PF1)
VB: D102.1, J103.20
VBAT: C112.1, D102.3, U102.1 (VBAT)
VDDA: C117.2, C118.2, C119.2, C120.2, L101.2, U102.20 (VREF+), U102.21 (VDDA)

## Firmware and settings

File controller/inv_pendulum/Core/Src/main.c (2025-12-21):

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
/* Includes ------------------------------------------------------------------*/
#include "main.h"
#include "dma.h"
#include "app_fatfs.h"
#include "iwdg.h"
#include "usart.h"
#include "rtc.h"
#include "spi.h"
#include "tim.h"
#include "gpio.h"

/* USER CODE BEGIN Includes */
#include "rip_config.h"
#include "user_setting.h"
#include "fonts.h"
#include "tft.h"
#include "functions.h"
#include <math.h>
#include <stdio.h>
#include <stdarg.h>
/* USER CODE END Includes */


/* USER CODE BEGIN PV */
float cmd_energy_norm, cmd_lqr_volt;
int total_cmd, cmd_energy, cmd_lqr, cmd_kick;

float alpha, alpha_shifted, alpha_dot, theta, theta_dot, voltage_input;

volatile PendulumState state = STATE_WAIT_BUTTON;
int kick_counter = 0;

int debug, emer, released, led_counter = 0;
static uint32_t last_log_time = 0;

RTC_TimeTypeDef current_time_rtc;
RTC_DateTypeDef current_date_rtc;
/* USER CODE END PV */

void SystemClock_Config(void);
/* USER CODE BEGIN PFP */
static inline float wrap_pi(float x);
static inline float wrap_2pi(float x);
void Pendulum_Display_Init(void);
/* USER CODE END PFP */

/* USER CODE BEGIN 0 */
void Debug_Printf(const char *format, ...) {
	char buffer1[128];
	va_list args;
	va_start(args, format);
	int len = vsnprintf(buffer1, sizeof(buffer1), format, args);
	va_end(args);

	if (len > 0 && len < sizeof(buffer1)) {
		HAL_UART_Transmit(&hlpuart1, (uint8_t*) buffer1, len, 100);
	}
}

/* USER CODE END 0 */

/**
  * @brief  The application entry point.
  * @retval int
  */
int main(void)
{

  /* MCU Configuration--------------------------------------------------------*/

  /* Reset of all peripherals, Initializes the Flash interface and the Systick. */
  HAL_Init();

  /* Configure the system clock */
  SystemClock_Config();

  /* Initialize all configured peripherals */
  MX_GPIO_Init();
  MX_DMA_Init();
  MX_TIM1_Init();
  MX_TIM2_Init();
  MX_TIM3_Init();
  MX_TIM4_Init();
  MX_SPI2_Init();
  MX_USART3_UART_Init();
  if (MX_FATFS_Init() != APP_OK) {
    Error_Handler();
  }
  MX_LPUART1_UART_Init();
  MX_TIM6_Init();
  MX_IWDG_Init();
  MX_RTC_Init();
  /* USER CODE BEGIN 2 */
	config_begin();
	config_begin_communication();
  /* USER CODE END 2 */

  /* Infinite loop */
  /* USER CODE BEGIN WHILE */
	while (1) {
    /* USER CODE END WHILE */

    /* USER CODE BEGIN 3 */
		HAL_IWDG_Refresh(&hiwdg);
		emer = HAL_GPIO_ReadPin(emergency_GPIO_Port, emergency_Pin);

		if (bluetooth_enabled) {
			HC05_Process(&hc05);
		}

	    if (lcd_display_enabled && LCD_Display_ShouldUpdate(&hlcd)) {
	        LCD_Display_Update(&hlcd);
	    }

	    /* SD LOGGING with RTC */
	    if (logging_enabled) {
	        uint32_t current_time = HAL_GetTick();

	        if ((current_time - last_log_time) >= 10) {
	            last_log_time = current_time;

	            RTC_TimeTypeDef rtc_time;
	            RTC_DateTypeDef rtc_date;
	            HAL_RTC_GetTime(&hrtc, &rtc_time, RTC_FORMAT_BIN);
	            HAL_RTC_GetDate(&hrtc, &rtc_date, RTC_FORMAT_BIN);

	            SD_Logger_WriteDataWithState(&sd_logger,
	                                        &rtc_time,
	                                        &rtc_date,
	                                        state,
	                                        alpha, alpha_dot,
	                                        theta, theta_dot);
	        }
	    }

        if (sd_logger_enabled && logging_enabled) {
            if (SD_Logger_ShouldFlush(&sd_logger)) {
                SD_Logger_FlushBuffer(&sd_logger);
            }
        }

	}
  /* USER CODE END 3 */
}

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
/* USER CODE BEGIN 4 */
static inline float wrap_pi(float x) {
	while (x > M_PI)
		x -= 2.0f * M_PI;
	while (x <= -M_PI)
		x += 2.0f * M_PI;
	return x;
}

static inline float wrap_2pi(float x) {
	while (x >= 2.0f * M_PI)
		x -= 2.0f * M_PI;
	while (x < 0.0f)
		x += 2.0f * M_PI;
	return x;
}

void HAL_TIM_PeriodElapsedCallback(TIM_HandleTypeDef *htim) {
	if (htim == &htim2) {
		QEI_get_diff_count(&motor_encoder);
		QEI_compute_data(&motor_encoder);
		QEI_get_diff_count(&pendulum_encoder);
		QEI_compute_data(&pendulum_encoder);

		total_cmd = cmd_lqr + cmd_energy + cmd_kick;

		voltage_input = total_cmd * MOTOR_VOLTAGE_LIMIT / 65535.0;

		alpha = wrap_2pi(pendulum_encoder.rads);
		alpha_dot = FIR_process(&alpha_dot_filter, pendulum_encoder.radps);
		theta = motor_encoder.rads;
		theta_dot = kf_update(&motor_filter, voltage_input, theta);

		alpha_shifted = wrap_pi(alpha - M_PI);

        if (led_matrix_enabled && hmatrix.is_initialized) {
        	LED_Matrix_DrawPendulum(&hmatrix, alpha, LED_MATRIX_COLOR_WHITE);
        	LED_Matrix_RefreshISR(&hmatrix);
        }

        if (lcd_display_enabled) {
            LCD_Display_IncrementCounter(&hlcd);
        }

		PendulumState current_state = state;

		switch (state) {
		case STATE_WAIT_BUTTON:
			if (emer) {
				state = STATE_EMERGENCY;
			}

			cmd_lqr = 0;
			if (++led_counter >= 100) {
				HAL_GPIO_TogglePin(LD2_GPIO_Port, LD2_Pin);
				led_counter = 0;
			}
			if (HAL_GPIO_ReadPin(B1_GPIO_Port, B1_Pin) == GPIO_PIN_SET) {
				kick_counter = 0;
				state = STATE_KICK;
				QEI_reset(&pendulum_encoder);
				QEI_reset(&motor_encoder);
				kf_clear(&motor_filter);
				total_cmd = 0;
				HAL_GPIO_WritePin(LD2_GPIO_Port, LD2_Pin, GPIO_PIN_RESET);
			}

			MDXX_set_range(&motor, 2000, 0);
			break;
		case STATE_KICK:
			kick_counter++;
			cmd_kick = (kick_counter < 250) ? 7000 : -7000;

			if (kick_counter < 500) {
				MDXX_set_range(&motor, 2000, cmd_kick);
			} else {
				cmd_kick = 0;
				state = STATE_SWINGUP;
			}
			break;
		case STATE_SWINGUP:
			if (fabsf(alpha_shifted) < 0.25) {
				cmd_energy = 0;
				cmd_kick = 0;
				state = STATE_LQR;
			} else {
				cmd_energy_norm = EnergyCtrl_Update(&swingup, alpha, alpha_dot);
				cmd_energy = (int) (cmd_energy_norm * 6500.0f);
				MDXX_set_range(&motor, 2000, cmd_energy);
			}
			break;
		case STATE_LQR:
			if (fabsf(alpha_shifted) > 0.5f) {
				cmd_energy = 0;
				state = STATE_WAIT_BUTTON;
				MDXX_set_range(&motor, 2000, 0);
			} else {
				LQR_SetState(&lqr_ctrl, theta, alpha_shifted, theta_dot,
						alpha_dot);
				cmd_lqr_volt = LQR_Update(&lqr_ctrl);
				cmd_lqr = (int) (cmd_lqr_volt * 65535.0f / MOTOR_VOLTAGE_LIMIT);
				MDXX_set_range(&motor, 2000, cmd_lqr);
			}
			break;
		case STATE_EMERGENCY:
			cmd_lqr = 0;
			MDXX_set_range(&motor, 2000, 0);
			QEI_reset(&motor_encoder);
			QEI_reset(&pendulum_encoder);
			kf_clear(&motor_filter);
			total_cmd = 0;
			HAL_GPIO_WritePin(LD2_GPIO_Port, LD2_Pin, GPIO_PIN_SET);

			if (emer == 0) {
				released = 1;
			}

			if (released
					&& HAL_GPIO_ReadPin(B1_GPIO_Port, B1_Pin) == GPIO_PIN_SET) {
				state = STATE_WAIT_BUTTON;
				HAL_GPIO_WritePin(LD2_GPIO_Port, LD2_Pin, GPIO_PIN_RESET);
				led_counter = 0;
				released = 0;
				debug = 0;
			}
			break;
		}
	}
}

void HAL_GPIO_EXTI_Callback(uint16_t GPIO_Pin) {
	if (GPIO_Pin == emergency_Pin) {
		state = STATE_EMERGENCY;
		released = 0;
	}
}

void HAL_UART_RxCpltCallback(UART_HandleTypeDef *huart) {
	if (huart == &huart3) {
		HC05_UART_RxCpltCallback(&hc05);
	}
}

void HAL_UART_TxCpltCallback(UART_HandleTypeDef *huart) {
	if (huart == &huart3) {
		HC05_UART_TxCpltCallback(&hc05);
	}
}

void HAL_UART_ErrorCallback(UART_HandleTypeDef *huart) {
	if (huart == &huart3) {
		HC05_UART_ErrorCallback(&hc05);
	}
}
/* USER CODE END 4 */
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


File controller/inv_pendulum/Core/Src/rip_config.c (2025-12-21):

#include "rip_config.h"
#include "main.h"
#include "lcd_display.h"
#include <string.h>
#include <ctype.h>
#include <stdio.h>

extern TIM_HandleTypeDef htim2;

/* LCD test function */
void LCD_Minimal_Test(void);

MDXX motor;

QEI motor_encoder;
QEI pendulum_encoder;

FIR alpha_dot_filter;
FIR theta_dot_filter;

EnergyCtrl swingup;

LQR_Controller lqr_ctrl;

KalmanFilter motor_filter;

LED_Matrix_Handle_t hmatrix;
HC05_Handle_t hc05;
SD_Logger_Handle_t sd_logger;
LCD_Handle_t hlcd;

float32_t K_matlab[4] = { -0.8197f, 11.3205f, -0.6469f, 1.1683f };

float32_t A[16] = {1.0f, 9.999812785357154e-04f, -1.149563041803406e-04f, 7.180678148697623e-06f,
                   0.0f, 0.999950617296464f,   -0.229910715302858f, 0.014322070901902f,
                   0.0f, 0.0f   ,   1.0f  , 0.0f,
                   0.0f,-0.004961131606500f, 5.718837195395508e-04f, 0.983689934032327f};

float32_t B[4] = {1.908889505894626e-07f,
                  5.718837195395508e-04f,
                  0.0f,
                  0.078991236957537f};

volatile uint8_t led_matrix_enabled = 0;
volatile uint8_t sd_logger_enabled = 0;
volatile uint8_t lcd_display_enabled = 0;
volatile uint8_t bluetooth_enabled = 0;
volatile uint8_t logging_enabled = 0;

extern void Debug_Printf(const char* format, ...);

void config_begin() {
    Debug_Printf("\r\nSystem Initialization\r\n");

    QEI_init(&motor_encoder, ENC_TIM1, ENC_PPR, ENC_FREQ, MOTOR_RATIO);
    QEI_init(&pendulum_encoder, ENC_TIM2, ENC_PPR, ENC_FREQ, MOTOR_RATIO);

    MDXX_GPIO_init(&motor, MOTOR1_TIM, MOTOR1_TIM_CH, MOTOR1_GPIOx, MOTOR1_GPIO_Pin);
    MDXX_set_range(&motor, 2000, 0);

    FIR_init(&alpha_dot_filter, TAPS, CUTOFF, SAMPLING_RATE);
    FIR_init(&theta_dot_filter, TAPS, CUTOFF, SAMPLING_RATE);
    EnergyCtrl_Init(&swingup, PENDULUM_MASS, PENDULUM_LENGTH, PENDULUM_INERTIA, GRAVITY, ENERYGY_GAIN);
    kf_init(&motor_filter, A, B, 1.0f, 0.0005f);
    LQR_Init(&lqr_ctrl, K_matlab, VOLTAGE_LIMIT);

    if (LED_Matrix_Init(&hmatrix) == HAL_OK) {
        led_matrix_enabled = 1;
        Debug_Printf("LED Matrix: ENABLED\r\n");
    } else {
        led_matrix_enabled = 0;
        Debug_Printf("LED Matrix: DISABLED\r\n");
    }

    if (SD_Logger_Init(&sd_logger) == HAL_OK) {
        sd_logger_enabled = 1;
        Debug_Printf("SD Logger: ENABLED\r\n");
    } else {
        sd_logger_enabled = 0;
        Debug_Printf("SD Logger: DISABLED\r\n");
    }

    if (LCD_Display_Init(&hlcd) == HAL_OK) {
        lcd_display_enabled = 1;
        LCD_Display_SetUpdateRate(&hlcd, LCD_UPDATE_DIVIDER);
        Debug_Printf("LCD Display: ENABLED\r\n");
    } else {
        lcd_display_enabled = 0;
        Debug_Printf("LCD Display: DISABLED\r\n");
    }

    Debug_Printf("\r\nInitialization Complete\r\n");
    Debug_Printf("LED Matrix: %s\r\n", led_matrix_enabled ? "ON" : "OFF");
    Debug_Printf("SD Logger: %s\r\n", sd_logger_enabled ? "ON" : "OFF");
    Debug_Printf("LCD Display: %s\r\n", lcd_display_enabled ? "ON" : "OFF");

    HAL_TIM_Base_Start(&htim1);
    HAL_TIM_Base_Start_IT(&htim6);
    HAL_TIM_Base_Start_IT(CONTROL_TIM);

}

void config_begin_communication() {
    if (HC05_Init(&hc05, &huart3, 9600) == HAL_OK) {
        HC05_SetCommandCallback(&hc05, HC05_CommandHandler);
        bluetooth_enabled = 1;

        const char *msg1 = "\r\n===== RIP Control System =====\r\n";
        const char *msg2 = "Type HELP for commands\r\n";
        const char *msg3 = "\r\n> ";

        HAL_UART_Transmit(&huart3, (uint8_t*)msg1, strlen(msg1), 1000);
        HAL_UART_Transmit(&huart3, (uint8_t*)msg2, strlen(msg2), 1000);
        HAL_UART_Transmit(&huart3, (uint8_t*)msg3, strlen(msg3), 1000);

        HC05_Start(&hc05);
    } else {
        bluetooth_enabled = 0;
    }
}
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

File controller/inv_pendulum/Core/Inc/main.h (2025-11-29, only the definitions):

#define B1_Pin GPIO_PIN_13
#define B1_GPIO_Port GPIOC
#define B1_EXTI_IRQn EXTI15_10_IRQn
#define RCC_OSC32_IN_Pin GPIO_PIN_14
#define RCC_OSC32_IN_GPIO_Port GPIOC
#define RCC_OSC32_OUT_Pin GPIO_PIN_15
#define RCC_OSC32_OUT_GPIO_Port GPIOC
#define RCC_OSC_IN_Pin GPIO_PIN_0
#define RCC_OSC_IN_GPIO_Port GPIOF
#define RCC_OSC_OUT_Pin GPIO_PIN_1
#define RCC_OSC_OUT_GPIO_Port GPIOF
#define SDA_Pin GPIO_PIN_0
#define SDA_GPIO_Port GPIOC
#define SCK_Pin GPIO_PIN_1
#define SCK_GPIO_Port GPIOC
#define C7_Pin GPIO_PIN_2
#define C7_GPIO_Port GPIOC
#define C6_Pin GPIO_PIN_3
#define C6_GPIO_Port GPIOC
#define RSTn_Pin GPIO_PIN_0
#define RSTn_GPIO_Port GPIOA
#define LAT_Pin GPIO_PIN_1
#define LAT_GPIO_Port GPIOA
#define LPUART1_TX_Pin GPIO_PIN_2
#define LPUART1_TX_GPIO_Port GPIOA
#define LPUART1_RX_Pin GPIO_PIN_3
#define LPUART1_RX_GPIO_Port GPIOA
#define LD2_Pin GPIO_PIN_5
#define LD2_GPIO_Port GPIOA
#define LCD_D1_Pin GPIO_PIN_4
#define LCD_D1_GPIO_Port GPIOC
#define LCD_D4_Pin GPIO_PIN_5
#define LCD_D4_GPIO_Port GPIOC
#define SB_Pin GPIO_PIN_0
#define SB_GPIO_Port GPIOB
#define SD_CS_Pin GPIO_PIN_1
#define SD_CS_GPIO_Port GPIOB
#define LCD_D7_Pin GPIO_PIN_2
#define LCD_D7_GPIO_Port GPIOB
#define LCD_RS_Pin GPIO_PIN_10
#define LCD_RS_GPIO_Port GPIOB
#define LCD_D6_Pin GPIO_PIN_11
#define LCD_D6_GPIO_Port GPIOB
#define LCD_D5_Pin GPIO_PIN_12
#define LCD_D5_GPIO_Port GPIOB
#define LCD_D3_Pin GPIO_PIN_6
#define LCD_D3_GPIO_Port GPIOC
#define LCD_WR_Pin GPIO_PIN_7
#define LCD_WR_GPIO_Port GPIOC
#define LCD_D2_Pin GPIO_PIN_8
#define LCD_D2_GPIO_Port GPIOC
#define emergency_Pin GPIO_PIN_9
#define emergency_GPIO_Port GPIOC
#define LCD_D0_Pin GPIO_PIN_10
#define LCD_D0_GPIO_Port GPIOA
#define T_SWDIO_Pin GPIO_PIN_13
#define T_SWDIO_GPIO_Port GPIOA
#define T_SWCLK_Pin GPIO_PIN_14
#define T_SWCLK_GPIO_Port GPIOA
#define C1_Pin GPIO_PIN_15
#define C1_GPIO_Port GPIOA
#define C3_Pin GPIO_PIN_10
#define C3_GPIO_Port GPIOC
#define C5_Pin GPIO_PIN_11
#define C5_GPIO_Port GPIOC
#define C2_Pin GPIO_PIN_12
#define C2_GPIO_Port GPIOC
#define C4_Pin GPIO_PIN_2
#define C4_GPIO_Port GPIOD
#define T_SWO_Pin GPIO_PIN_3
#define T_SWO_GPIO_Port GPIOB
#define LCD_CS_Pin GPIO_PIN_4
#define LCD_CS_GPIO_Port GPIOB
#define LCD_RST_Pin GPIO_PIN_5
#define LCD_RST_GPIO_Port GPIOB
#define LCD_RD_Pin GPIO_PIN_6
#define LCD_RD_GPIO_Port GPIOB
#define C0_Pin GPIO_PIN_7
#define C0_GPIO_Port GPIOB

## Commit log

2025-11-06 PCB v1
    [RIP_ExtensionBoard.kicad_pcb, RIP_ExtensionBoard.kicad_sch, RIP_STM32G474RET6.kicad_pcb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]
2025-11-06 fix footprint
    [RIP_ExtensionBoard.kicad_pcb, RIP_ExtensionBoard.kicad_sch]
2025-11-06 export gerber
    [RIP_ExtensionBoard-B_Cu.gbr, RIP_ExtensionBoard-B_Mask.gbr, RIP_ExtensionBoard-B_Paste.gbr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]

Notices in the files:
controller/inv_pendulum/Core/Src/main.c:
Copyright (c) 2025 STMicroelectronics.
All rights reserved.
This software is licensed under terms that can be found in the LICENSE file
